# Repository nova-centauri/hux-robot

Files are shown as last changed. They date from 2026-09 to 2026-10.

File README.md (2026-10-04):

# Hux — V1-PROOF

**Build a small wheeled robot that balances, drives and adjusts its height for under $1,000.** The stair project is parked. V1-PROOF is the active model as of 2026-09-28. Old requirements do not gate this build.

| Design target | V1-PROOF |
| --- | --- |
| Cash budget | **$900 planning ceiling**, including $100 shipping/tax and $125 repair contingency; strictly under $1,000 |
| Mass | **2.5 kg target; 3.0 kg maximum**, including battery |
| Actuators | **Four:** two encoder wheel gearmotors, one small leg servo per side |
| First milestone | Pin the legs; balance using only the two wheel motors |
| Size | Approximately **28–31 cm high, 25.5 cm wide**, 10 cm rubber wheels |
| Motion | Indoor mobility; 0.25 m/s cruise, 0.15 m/s on qualified shallow uneven surfaces; approximately 28 mm leg-height adjustment |
| Reuse | Existing controller, IMU, manual input, battery/charger and shop stock when confirmed |
| Finish line | Repeatable balance, five movement types, controlled stops, bounded disturbances and slow height changes |

Start with the **[V1-PROOF plan](docs/v1-proof.md)**, **[model page](tools/living-drawings/index.html)**, **[2D layout](cad/layouts/v1-proof.svg)** and **[budget](docs/bom.md)**. The budget includes replacement allowances because the available parts are still unconfirmed. The [selected hardware](docs/v1-proof-hardware.md), [simulation report](docs/v1-proof-simulation.md), [interactive replay](tools/living-drawings/proof-simulation.html), [drivable 3D sandbox](tools/living-drawings/proof-sandbox.html) and [physical validation protocol](docs/v1-proof-validation.md) define this revision. This is not a fully quoted cart or a validated physical robot.

The scope has no stairs, one-wheel stance, jumps, rough terrain, onboard cameras, autonomy or required onboard Linux computer. Bounded push recovery and shallow indoor irregularities are now explicit qualification targets. In-wheel BLDC, CAN, 8S, carbon spars and the previous large head are no longer requirements. A geared brushed wheel drive is permitted for this proof.

## Working documents

- [Mechanical testing layout and timeline](tools/living-drawings/mechanical-tests.html): movable side/end views, the R01 render, test steps and dated session drafts.
- [Single-leg bench preparation](docs/one-leg-bench.md), [printable geometry template](cad/layouts/one-leg-bench-template.svg) and [session record](docs/checklists/one-leg-bench-session.md)
- [Requirements](docs/requirements.md) and [decision log](docs/decisions.md)
- [Mechanical](docs/mechanical.md), [electronics](docs/electronics.md), [software](docs/software.md)
- [Parts to confirm](docs/parts-on-hand.md) and [next work](NOTES.md)
- [Build checklists](docs/checklists/), [sizing calculations](docs/v1-proof-sizing.md)
- [Writing standard](docs/writing-standard.md): all active text obeys Simplified Technical English
- [Model source and checks](tools/v1-proof/README.md)

## Living website

The website organizes **V1-PROOF** into Overview, Mechanical, Electrical, Build & test, Parts & budget, and Documents. The interactive tools and the rendered guides have the same navigation. Mechanical includes [joint close-up studies](tools/living-drawings/joints.html). Electrical contains the [source-checked EL-01–04 wiring atlas](tools/living-drawings/electrical.html), with zoomable vector sheets and a printable PDF. [Pinout verification and open circuit decisions](docs/wiring-atlas.md) keep the physical release boundary.

The [build board](tools/living-drawings/build.html) tracks the supported single-leg exercise, the milestone gates and the dated updates. [Parts and budget](tools/living-drawings/parts.html) keeps procurement separate. **V0-GENESIS** remains the original plan archive. Browser bench notes are local drafts. The shared plan is in `tools/living-drawings/plan-data.json` with its referenced documents.

Run `npm run build` and `npm run test:site` from `tools/living-drawings`. Then serve or publish `dist/site`. Markdown guides become real HTML pages with version navigation. Refer to [website maintenance](docs/site-maintenance.md) for the update and preview workflow.

## Parked work

The [V0-GENESIS archive](docs/archive/stair-v1/README.md) keeps the earlier plans (historically named STAIR-V1). The earlier research, the H1 layout, the actuator studies and the old eight-axis simulator remain available as historical work. They do not define V1-PROOF, and this proof chassis has no promised stair upgrade path.

Regenerate the active model with `python3 tools/v1-proof/review.py --write`. Check it with `python3 tools/v1-proof/test_review.py` and `python3 tools/v1-proof/review.py --check`. From `tools/living-drawings`, `npm test` checks the active model. `npm run test:legacy` keeps the old regression suite. This repository contains the plan, the size calculations and a reproducible pinned-leg 3D simulation study.

**2026-10-02: the 30:1 gearmotor and the DRV8874 drivers are received, and the parts are 3D printed**, per the user. Start the [first mechanical fit session](docs/checklists/2026-10-02-mechanical-fit.md). The paid record covers one Pololu 4752 gearmotor and one Pololu 4035 driver. The total delivered driver count remains to confirm. Two ST3215 servos are paid, with the 12 V variant confirmed and the arrival unreported.

**2026-10-03: one Pico 2 with pre-soldered headers is received. The LSM6DSO IMU is also received, untested, per the user.** Start the [Pico USB/LED check](docs/checklists/2026-10-03-pico-bringup.md). The $30.58 controller/IMU order brings the **recorded spend to $173.70** and leaves **$726.30** under the $900 plan. The charge breakdown of the new order is unshown.

These actuator models are locked for V1-PROOF. A second wheel motor is still necessary. Refer to [paid orders](docs/purchases.md), [motor connections](docs/v1-proof-hardware.md) and [how the intelligence works](docs/software.md). RobStride actuators are intended for the future full-size Hux. Fit, load, firmware and balance qualification remain open. [MIT](LICENSE).

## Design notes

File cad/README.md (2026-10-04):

# Hux CAD and layouts

Active: [V1-PROOF envelope sketch](layouts/v1-proof.svg), generated from [model.json](../tools/v1-proof/model.json). It shows side, front and plan envelopes plus the simple parallel-link leg. It is not a fabrication drawing or a clearance validation.

For bench geometry checks, use the [1:1 single-leg geometry template](layouts/one-leg-bench-template.svg) with the [bench plan](../docs/one-leg-bench.md). Print at actual size and make sure that the 100 mm scale is correct. The template marks pivot centers for a paper/scrap mockup. Shaft holes, structural sections, lateral offsets and purchased-part mounts are not released.

**2026-10-02 — parts printed and motor/drivers received per the user:** start the [first mechanical fit session](../docs/checklists/2026-10-02-mechanical-fit.md). The [V1-PROOF R01 passive kit](prints/v1-proof-r01/README.md), drafted on September 29 for the Bambu X1C and PLA, has eight STL part types. The kit also has a Blender project that uses the 110 mm link / 40 mm pivot geometry. Confirm the printed revision and material, measure the fit coupon if it is printed, and check the actual M4 fits. Printed sections and mounts remain provisional. No fit, load test or bench milestone is complete.

Next: measure the available parts, mock up the pinned-leg chassis, then detail bearings, pivots, reductions and cables for one leg. Keep 2D layouts before detailed 3D work. Suitable scrap/COTS stock is welcome. There is no carbon or custom in-wheel motor requirement.

[H1](layouts/head-h1.svg), the [stair engineering review](../docs/head-and-leg-review.md), old sheets and downloaded vendor geometry are parked references. Vendor files in `vendor/` remain untouched and do not establish ownership. No released Hux custom parts exist.

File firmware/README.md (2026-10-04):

# Firmware

No embedded implementation exists yet. **2026-10-03:** one Pico 2 with pre-soldered headers is received, untested. Start the [USB/LED bring-up checklist](../docs/checklists/2026-10-03-pico-bringup.md) with the official vendor examples.

V1-PROOF targets C/C++ with `PICO_BOARD=pico2`. The target also includes the received LSM6DSO IMU over SPI, two encoder wheel drivers and, later, two small leg servos. Sensor qualification is not complete. The LSM6DSO IMU replaces the earlier LSM6DSOX selection. Use the register initialization of the LSM6DSO IMU. [Software contract](../docs/software.md) and [software checklist](../docs/checklists/software-bringup.md).

Robot modes are `DISARMED`, `BALANCE`, `DRIVE`, `FAULT`. A proposed `BENCH_ARMED` state supports a rigidly fixed single leg and a lifted wheel before balance. Refer to the [bench controls and test plan](../docs/one-leg-bench.md). No bench controller exists. CAN, one-wheel stance modes and stair control belong to the parked project.

First jobs can be readback, bounded actuator motion and fault checks in the fixture. Then sensor logs and pinned-leg balance can follow.

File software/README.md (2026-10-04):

# Companion software

V1-PROOF needs no onboard companion computer. Use an available laptop for logs and optional timed manual commands. An available Pi can help off-robot, but cameras, ROS, pathfinding and new compute purchases are deferred.

The MCU runs the balance loop. [Active software plan](../docs/software.md). No companion implementation exists yet.

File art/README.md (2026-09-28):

> **PARKED STAIR-V1 — 2026-09-28.** This is historical research, not an active requirement, BOM or build gate. [V1-PROOF](../docs/v1-proof.md) governs current work.

# Art

Exploratory visuals for Hux, made to look at before any accurate model work. These are concept renders and image-to-mesh studies. They are not measured geometry, they do not meet the 2D-layout gate, and they stay out of `cad/`.

Proportions, joint axes, and part envelopes still live in `docs/mechanical.md` and the living drawings. The same files are on the [media page](../tools/living-drawings/media.html).

## Concepts

| File | What it shows |
| --- | --- |
| `concepts/hux-standing.jpg` | Studio three-quarter. Style anchor: carbon-tube legs, aluminum knee linkages, black cubes at the hips, spokeless disc hubs, battery box, camera on top. |
| `concepts/hux-knee-actuators.jpg` | Same machine with black cubic actuators at the knees in place of the linkage plates. |
| `concepts/hux-straight-leg.jpg` | Earlier packaging sketch: one spar per leg, finned hip motors, no knee. |
| `concepts/hux-side.jpg` | Side view. The camera sits slightly off a true elevation, so both wheels still show. |
| `concepts/hux-workshop.jpg` | The standing robot in a shop, with stairs behind it. |
| `concepts/hux-stairs.jpg` | Climb, one wheel on a higher tread. |
| `concepts/wheel.jpg` | Wheel study. The motor sits beside the hub in this sketch. |
| `concepts/leg.jpg` | One leg: paired carbon tubes, linkage knee, cube at the hip, disc wheel. |
| `concepts/torso.jpg` | Hip beam, two side cubes, battery, camera. Legs removed. |

## Models

Rough textured meshes generated from the isolated shots. Each file is a single mesh, on the order of a million triangles, 45–74 MB. Fasteners melt together, edges go soft, and a little floor tone can bake into the texture. Any glTF viewer will open them.

| File | Source image |
| --- | --- |
| `models/hux.glb` | `hux-standing.jpg` |
| `models/leg.glb` | `leg.jpg` |
| `models/wheel.glb` | `wheel.jpg` |
| `models/torso.glb` | `torso.jpg` |

## Where the pictures drift from the mechanical notes

- Nothing here is to scale. The paper envelope is about 24 in tall and 14 in wide, with 6 in wheels.
- The battery is drawn high on the torso. The mass sketch wants it low and central.
- Several shots put the wheel motor beside the tire. The intent is a motor in the hub.
- Hip roll and hip swing are not drawn as two separate joints.
- Small print on the battery, tire sidewalls, and plates is gibberish. Ignore it.

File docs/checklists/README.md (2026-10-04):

# V1-PROOF build checklists

The active checklists are for the small, four-actuator indoor proof with bounded disturbance and shallow-surface qualification. [Finish line](../v1-proof.md#finish-line).

- [Mobility and disturbance protocol](../v1-proof-validation.md)
- [Hardware decisions and interfaces](../v1-proof-hardware.md)
- [Single-leg bench plan](../one-leg-bench.md) and [copyable session record](one-leg-bench-session.md)
- [First mechanical fit session, opened 2026-10-02](2026-10-02-mechanical-fit.md): the motor/drivers and the printed parts are received. The passive checks are ready. No results are recorded yet.
- [Living mechanical layout and test timeline](../../tools/living-drawings/mechanical-tests.html) and [recording workflow](../mechanical-testing.md).
- [Mechanical stages and trials](mechanical-v1.md)
- [Electronics bring-up](electronics-bringup.md)
- [Software bring-up](software-bringup.md)
- [Pico 2 USB bring-up, opened 2026-10-03](2026-10-03-pico-bringup.md): the controller is received. The LSM6DSO IMU is also received, untested, per the user. The BOOTSEL, LED and optional serial results are not recorded yet.

Check a box only after physical evidence exists. Previous stair checklists are [parked](../archive/stair-v1/checklists/README.md).

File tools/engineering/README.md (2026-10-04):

> **PARKED STAIR-V1.** [V1-PROOF](../v1-proof/README.md) is the active numerical model. This publisher cannot overwrite the proof BOM.

# Parked stair engineering candidate — revision 2026-09-28-B

No components are purchased. There is no fabrication or full actuator-set release. Start with
[the review](../../docs/head-and-leg-review.md) and
[decisions](../../docs/decisions.md). No third-party Python packages are necessary.

```sh
python3 tools/engineering/review.py --write
python3 tools/engineering/test_review.py
```

`baseline.json` owns head allocations, mass estimates, geometry, study overrides,
electrical assumptions and the historical tube reference. `bom.json` owns budget
rows and their procurement gates. Generated outputs:

- `docs/research/head-leg-results.json`: results and 91-frame paths for the compact, extended and narrow-entry candidates. The other cases have summaries only.
- `cad/layouts/head-h1.svg`: dimensioned head allocation.
- `tools/living-drawings/engineering.html`: parked stair review page.
- `docs/archive/stair-v1/bom.md`: archived budget, computed from quantities and unit ranges.

Coordinates in the input and result positions are **mm**, X forward, Y left, Z up.
The body datum is midway between the hip-roll axes. Inertia is kg·m², torque N·m,
mass kg, force N. `angles_deg` orders hip roll, hip pitch, knee flexion, ankle roll.
Positive pitch puts the thigh rearward. The shin pitch is `hip_pitch − knee`.

Left and right legs use opposite lateral offsets. In a selected upright wheel
pose, the assumed ankle counter-roll equals negative hip roll. This assumption depends on an
unbuilt pitch-level carrier, not on a motor bolted to the shin.

`leg` is the compact 24-inch target. The `studies.taller_leg_overrides` and then
`studies.extended_leg_overrides` form the approximately 27-inch wide-entry comparison. The `studies.narrow_stance_overrides` produce the narrow comparison: 120 mm track during the step plus a nominal 355.6 mm moving-width gate.

`neutral_wheel_outside_width_mm` defines the fixed axle/yoke offset at zero roll, not the swept envelope. The preferred candidate uses the 9.5-inch link override with that narrow stance, for 25.94-inch height.
The 24/25-inch narrow cases remain rejected. The high-mass
case adds the explicit 0.60 kg head uncertainty. Neither variant silently replaces
the requirement. The `release` flags of the report stay false, whatever the screen scores are.

The screen solves whole-robot static COM, split-offset spatial IK and gravity joint
moments. A layered search connects feasible poses. Interpolation checks the limited
clearance model between samples. The screen does not solve actuator dynamics, real contact
compliance/friction, thermal duty, full swept solids, nosings, descent or the actual
ankle linkage. The old eight-axis JavaScript simulation remains a labeled historical
experiment. Its tests intentionally assert that its stair candidate fails.

When you accept a design revision, update the inputs and the dated decision entry. Then
regenerate the outputs and check the physical invariants. Update requirements, CAD joint
centers, inertia/contact model, BOM, firmware map and limits together. Never
promote an unmeasured mass or a vendor heat-sink rating into a hardware fact.

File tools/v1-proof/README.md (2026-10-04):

# V1-PROOF numerical studies

Four actuators, 2.5 kg target / 3.0 kg maximum, indoor mobility and bounded disturbances, strictly under $1,000. [Plan](../../docs/v1-proof.md) · [hardware decisions](../../docs/v1-proof-hardware.md).

```sh
python3 tools/v1-proof/review.py --write
cd tools/living-drawings
npm ci
npm run simulate
npm test
```

`model.json` owns hardware selections, dimensions, mass, electrical screens, operation targets and budget. Standard-library `review.py` generates the BOM, the size calculations, the SVG, the results and the plan data for the browser. Its `--check` finds stale outputs.

`sim.js` builds the pinned-leg 3D rigid-body model and controller with the pinned Rapier 0.20.0 dependency of the repository. It imports no legacy stair motors, masses or joint model. `run_sim.js` runs 23 scenarios across 17 configurations, six challenge cases, five timestep comparisons and six separate CoM-adjustment checks. `--quick` runs nominal/challenge/convergence only. Use `--write` without `--quick` for published evidence. `--check` makes sure that the saved source hashes are correct.

`report_sim.py` generates the [evidence report](../../docs/v1-proof-simulation.md). [Interactive replay](../living-drawings/proof-simulation.html).

**3D sandbox.** [`proof-sandbox.html`](../living-drawings/proof-sandbox.html) loads this same `sim.js` in the browser (`HuxProofSimFactory(RAPIER, model)`). You drive it from the keyboard or a gamepad at full scale, on the fixtures of the physical protocol (3° grade, 3° cross-slope, 5 mm bumps, 3 mm seam, 20 mm challenge threshold). [`proof-sandbox-core.js`](../living-drawings/proof-sandbox-core.js) adds only the fixtures, lane starts, robot-frame shoves, fall detection and a slow leg-height preview. `test_sandbox.js` checks it headless and runs in `npm test`. The leg preview re-places the CoM and pitch trim at 10°/s. The sandbox does not model servo dynamics, so legs that move are not evidence.

The sandbox adds nothing to `sim-results.json`. The page opens correctly straight from disk. three.js and Rapier load from jsDelivr.

`npm test` covers budgets/geometry plus gravity without control, mass, contact, voltage/speed/current bounds, balance-priority steering, signed maneuvers and deterministic reruns. The full sweep is explicit with `npm run simulate`. Failed cases remain in the report. `sim-tuning-history.json` keeps the weaker results of the initial controller.

The simulation assumes delayed attitude estimates and bounded torque response. It does not implement raw IMU fusion, MCU firmware, a thermal model, regenerative power electronics or powered leg dynamics. Read the assumptions of the report before you quote outcomes. All [physical tests](../../docs/v1-proof-validation.md) remain open. The previous stair model is parked separately.

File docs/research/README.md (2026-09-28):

> **PARKED STAIR-V1 — 2026-09-28.** This is historical research, not an active requirement, BOM or build gate. [V1-PROOF](../v1-proof.md) governs current work.

# Research first

**Current engineering baseline (2026-09-28):** [head and leg review](../head-and-leg-review.md), [reproducible numerical results](head-leg-results.json), [decision log](../decisions.md). Older research below is dated evidence, not current purchasing or fabrication authority. No Hux components purchased.

Hux is still early R&D. **Study before we build.** Watch, read, extract control and stair heuristics, then decide what to adapt versus rewrite. Do not vendor James Bruton / [XRobots](https://github.com/XRobots) trees into this repo yet. Do not spend. Flight controller stays **TBD**.

This packet is the working study set. It does not replace [`../requirements.md`](../requirements.md) or [`../vision.md`](../vision.md).

| Doc | What it is |
| --- | --- |
| [model-corrections.md](model-corrections.md) | Implemented geometry, contact, actuator, parking and reporting fixes; current regression results and remaining design work. |
| [real-world-validation.md](real-world-validation.md) | 2026-09-23 audit: spatial reach inconsistency, CoM versus hip torque, actuator/contact limits, reproduced tests, and physical validation sequence. Read before using earlier sizing or stair claims. |
| [xrobots.md](xrobots.md) | Curated XRobots shortlist, why each matters, study order |
| [inspiration.md](inspiration.md) | Steve's shares — Roadrunner, FrRonconi student balancer, Serra / Build Some Stuff, Tazer, Stompy, Diablo, SpdrBot; inspiration only |
| [roadrunner.md](roadrunner.md) | RAI Institute Roadrunner — lab wheeled biped; watch alongside Hattori |
| [actuators-legs.md](actuators-legs.md) | Axis-role trade; hip roll in V1; servo vs stepper TBD; GIM8108-8 candidate |
| [tazer-lessons.md](tazer-lessons.md) | Tazer wheeled biped — learn from the mistakes (anti-patterns) |
| [stompy-sim2real.md](stompy-sim2real.md) | Stompy week-build RL walker — CAD/reality match, shared zero; **not** RL walking for Hux V1 |
| [diablo.md](diablo.md) | Diablo (DDTRobot) — commercial wheeled-leg; LQR + DD; steal split brain / height states; **do not buy** |
| [spdrbot.md](spdrbot.md) | SpdrBot — Isaac Sim / Lab 4-leg spider; Fusion→URDF→USD; RL then hand gait; Phase E pipeline lessons, **not** a spider |
| [leg-geometry.md](leg-geometry.md) | Leg math. Wheel settled at **6" OD** on a **9.5" × 9.5"** step. Walker wheel is a bench donor. |
| [stair-climb-dynamics.md](stair-climb-dynamics.md) | Corrected spatial feasibility, rejected stair candidate, and limits of the historical planar load estimates. |
| [sim-sandbox.md](sim-sandbox.md) | Corrected tire/contact and drive models, supported parking guard, regression results, and remaining single-support failures. |
| [one-leg-stance.md](one-leg-stance.md) | Frontal-plane mechanics of the hip-roll weight shift (24.7°, 8.3 N·m hold), why a static one-wheel stand is an acrobot with millimetres of capture region, and the dynamic single-support flight budget the stair needs (≤ 0.3 s). |
| [compute-stack-review.md](compute-stack-review.md) | 2026-09-26 review of the F765-Wing / SimpleFOC / Pi 5 bench stack and the Jetson question — no CAN on the Wing, actuator bus picks the MCU, Jetson is a P5 perception buy, not V1 |
| [actuator-shortlist.md](actuator-shortlist.md) | 2026-09-26 decision framework and candidates on Hux's own numbers — RobStride 00/02/05 shortlist, the 24 V floor that pushes the pack to 8S, CAN bus math, runtime vs pack size |
| [knee-linkage.md](knee-linkage.md) | 2026-09-26 — knee actuator at the joint vs at the hip through a linkage vs no knee (four-bar / five-bar legs à la StepByStep, Ascento, T-REX); planar check on the settled draw; keep 2 DoF per leg, no five-bar, draw the hip-driven knee on the 2D sheet |
| [study-plan.md](study-plan.md) | Phased checklist before hardware (Phases A–D; Phase E twin / dojo is a later horizon) |

Decision log (not research, but the lock list): [`../decisions.md`](../decisions.md).

Inspiration already in requirements: [Alex Hattori — STRIDE wheeled biped V2](https://www.alex-hattori.com/blog/wheeled-biped-v2).

Steve's shares (inspiration only; not a build source): [inspiration.md](inspiration.md) — [Roadrunner](roadrunner.md) (lab), the FrRonconi 3-month student two-leg/wheel balancer (closer Hux vibe), Serra / Build Some Stuff (steal packaging), [Tazer](tazer-lessons.md) (learn from the mistakes), [Stompy](stompy-sim2real.md) (CAD → sim → real; **not** an RL-walking requirement), [Diablo](diablo.md) (commercial wheeled-leg; **do not buy**; keep R18), and [SpdrBot](spdrbot.md) (Isaac Sim / Lab pipeline for the Phase E horizon; **not** a spider; **not** Isaac before `TWO_WHEEL`).

## Stance

1. **Learn the lineage** — RobotX (wheeled biped / dynamic balance), then TallBalancer and SonicRobot for IMU → PID → wheel-torque and remote patterns.
2. **Map stairs** — XRobots Stairs is a different mechanism. Steal heuristics, not geometry. Pair it with Hattori (and [Roadrunner](roadrunner.md); see [inspiration.md](inspiration.md)) for Hux's lift → one-leg balance → plant cycle on a **~9.5"** riser. Serra is packaging, not stairs.
3. **Decide license + adapt vs rewrite** — Steve decides. Do not relicense Hux to absorb copyleft code, and do not pretend GPL/LGPL sources are MIT.
4. **Only then** print a wheel-leg fit-check. Mechanical V1 is Phase D, not the next commit.

No purchases until Steve asks. Prefer parts already on hand. Do not invent a BOM from upstream parts lists (SonicRobot's README is a study aid, not a Hux shopping list).

## How we cite and adapt upstream

Respect each upstream license. XRobots repos are **not** one license. RobotX is the copyleft tripwire for this phase.

### Cite

When a note, sketch, or later file is informed by upstream, record:

- Project name and org (`XRobots/RobotX`, Hattori STRIDE V2, RAI Roadrunner, FrRonconi / student balancer, Build Some Stuff / Serra, Tazer, Stompy / Kayden Knapik, Diablo / Direct Drive Tech, SpdrBot / Indystry, …)
- URL (repo, playlist, or post)
- License as stated by the author **and** the `LICENSE` file if they disagree
- What we took (idea, heuristic, control topology) versus what we did **not** copy

### Study vs vendor

| Allowed now | Not allowed yet |
| --- | --- |
| Watch playlists, read CAD/code in *their* repos | Copy CAD, firmware, or large trees into Hux |
| Notes, diagrams, and checklists in `docs/research/` | Treat upstream parts lists as a Hux BOM |
| Rewrite a loop from understanding (clean-room) | Drop GPL/LGPL sources next to our MIT tree |
| Link and quote short facts with attribution | Relicense anyone's code, including Hux itself |

Vendoring or adapting code is a **Phase C** decision. Until Steve picks a path, this repo stays MIT documentation and empty layout.

### RobotX is GPL3 — implications for MIT Hux

Hux is [MIT](../../LICENSE) (Steve Barrett, 2026).

[XRobots/RobotX](https://github.com/XRobots/RobotX) README states:

> All CAD and code is licensed under GPL3.

The repo also ships an **LGPL-3.0** `LICENSE` file. GitHub therefore labels the repo LGPL-3.0. **Do not resolve that conflict in Hux's favor.** Conservative reading for this phase: treat RobotX CAD/code as **GPL-3.0** as the author wrote in the README, and treat the LGPL file as an unresolved ambiguity Steve must look at before any vendor/adapt.

If we later **vendor or adapt** RobotX (or other GPL) code into Hux:

- We **cannot** relicense that material as MIT.
- A combined Hux tree that includes GPL-3.0 code is typically distributable only under GPL-3.0 (copyleft applies to the derivative).
- Even if the LGPL file controls, modified RobotX sources stay copyleft; LGPL is not a free pass to relicense or to hide provenance.
- MIT Hux and GPL RobotX can coexist as **separate** repos we study. Mixing them in one tree is the problem.

**Do not relicense Hux (MIT → GPL) or relicense upstream (GPL → MIT) without Steve deciding.** Phase C exists so that decision is explicit.

Other copyleft in the shortlist (still study-only):

- [XRobots/SonicRobot](https://github.com/XRobots/SonicRobot) — GitHub license **GPL-2.0** (closest brushless + balance electronics lessons)
- [XRobots/BalancingStrandbeest](https://github.com/XRobots/BalancingStrandbeest) — **GPL-3.0** (optional)

Several secondary XRobots repos are MIT (TallBalancer, Stairs, YouCanBuildBiPed, BallWheels, BeltWheelRobot, Ball-BIke, Mid-Walker). MIT-to-MIT adaptation still needs attribution and a Phase C yes; it does not force Hux off MIT.

Watching, learning, and rewriting from understanding is the default path that keeps Hux MIT. Copying RobotX or SonicRobot sources is the path that forces a license decision.

## Out of scope for this packet

- Locking an FC
- A Hux BOM or shopping list
- Vendoring `XRobots/*`
- Starting the first wheel-leg before Phase D
- Opening Blender before 2D layouts (R23)
- Changing [`../vision.md`](../vision.md) without a Steve decision (log it in [`../decisions.md`](../decisions.md))

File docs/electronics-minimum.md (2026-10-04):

# Minimum electronics — V1-PROOF

The active minimum is **one MCU + IMU, two encoder wheel motors, two bidirectional H-bridges, a timed manual input link, and a compatible battery/charger**. **The minimum also includes protected logic power.** Add two small leg servos and their interface/rail after pinned-leg balance works.

Start with the equipment confirmed in [parts-on-hand.md](parts-on-hand.md). There is no required Pi, CAN network, 8S pack, camera or separate pose computer. The [electronics plan](electronics.md) owns the interfaces and the power qualification. The [budget](bom.md) covers replacements. The former eight-axis minimum is [parked](archive/stair-v1/electronics-minimum.md).

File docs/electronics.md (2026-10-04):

# V1-PROOF electronics

**Selected baseline: Pico 2, the LSM6DSO IMU on SPI, two DRV8874 drivers and two ST3215 servos (12 V variant).** [Exact interfaces, proposed GPIO map, component sources and qualification gates](v1-proof-hardware.md). Confirmed equivalent equipment on hand can reduce the spend only after it meets the same contract. No onboard Linux computer or camera is necessary.

The [Electrical page](../tools/living-drawings/electrical.html) now contains the color-coordinated **EL-01–04 wiring atlas**, with an enlarged vector viewer and a printable PDF. The [source checks and detailed pin maps](wiring-atlas.md) separate the vendor-confirmed pinouts from the proposed GPIO assignments and the unresolved circuits. This is a build-plan drawing. The physical harness and the power-protection release remain open.

**Status, 2026-10-02:** the user reports that the 30:1 motor and the DRV8874 drivers are received and that the parts are printed. Receipts cover one Pololu 4752 gearmotor and one DRV8874 driver. The total received driver count remains to confirm. Two ST3215 servos are ordered, with the 12 V variant confirmed and the arrival unreported. A second wheel motor is still required. Confirm the driver coverage before you buy another driver.

The controller, IMU, adapters and power electronics remain purchase-unconfirmed. [Receipts and delivery status](purchases.md). Start with the [passive mechanical fit checks](checklists/2026-10-02-mechanical-fit.md). This wiring plan still waits for assembly and bench checks.

**2026-10-03:** one Pico 2 with pre-soldered headers is received, untested. The user reports that the LSM6DSO IMU is also received, untested. It replaces the earlier Adafruit LSM6DSOX selection. Start the [board-only USB/LED checks](checklists/2026-10-03-pico-bringup.md). Before you connect the sensor wires, examine the received IMU pads/jumpers and use 3.3 V power/logic.

## What will the motor plug into?

**Each Pololu 4752 gearmotor connects to its own DRV8874 driver (an H-bridge) through a breakout harness.** The driver switches the battery power through the motor. The Pico 2 sends low-power direction/PWM commands. The encoder wires of the motor return the movement feedback to the Pico 2 through level conversion.

The supplied connector of the Pololu 4752 gearmotor is a six-position female header at 2.54 mm pitch. It contains both the motor wires and the encoder wires. It needs a correctly wired mating header/harness. It is not a ready-made Pico 2 plug or servo-bus plug. [Pololu motor connector and wire reference](https://www.pololu.com/product/4752).

| Motor lead | Planned connection |
| --- | --- |
| Red | Driver OUT1 motor terminal |
| Black | Driver OUT2 motor terminal; this is a switched motor lead, not encoder ground |
| Green | Encoder ground / common logic reference |
| Blue | Regulated 5 V encoder supply |
| Yellow | Encoder A → 5 V-to-3.3 V level conversion → Pico encoder input |
| White | Encoder B → 5 V-to-3.3 V level conversion → Pico encoder input |

Repeat for the other wheel. Make sure of the connector orientation by wire function. Establish the forward/encoder sign of each wheel while the wheel is lifted. The harness, the lock/strain relief and the high-current connections still need fabrication. Keep the motor current out of breadboards and MCU supply pins. The proposed Pico 2 GPIO assignment is in the [hardware plan](v1-proof-hardware.md#interfaces-that-must-be-built-correctly).

The first driver for this motor was in the same Pololu shipment as the motor. The user reports that both are received, and the total driver count is not yet confirmed. The driver takes fused, switchable motor power at VIN/GND. It accepts the 3.3 V signals of the Pico 2: PWM to EN, direction to PH, with PMODE grounded. Its SLEEP input is the watchdog/kill-gated output-disable path.

The driver needs soldered connections or headers. It is a separate power board. Set and measure the current limit before you run a motor. [Pololu driver connections](https://www.pololu.com/product/4035).

**The ST3215 servo uses a different connection:** the protected 9 V servo branch supplies the power. A compatible half-duplex TTL interface carries the serial commands and the feedback between the servo bus and the Pico 2 UART. Assign distinct servo IDs and examine the received cable pinout before you power either unit. An H-bridge is for the brushed wheel motors. Each ST3215 servo already contains its own motor control electronics. The interface/adapter is still to be confirmed.

## Power and command paths

```text
3S pack -> fuse + physical actuator-power cut
  -> two DRV8874 H-bridges -> Pololu 4752 encoder gearmotors
  -> regulated/protected 9 V branch -> two ST3215 leg servos
  -> separate 5 V logic regulator -> Pico 2 + 3.3 V IMU/interface logic
Pico <- SPI IMU + 5 V encoder signals through level conversion
Pico <- both driver current/fault signals + divided pack voltage
Pico -> PWM/direction + watchdog/kill-gated SLEEP -> wheel drivers
Pico <-> half-duplex UART transceiver -> servo bus
Pico <- timed manual commands / deliberate arm
Pico <-> USB serial -> existing laptop logging/gamepad
```

## Power and interfaces

Keep the motor/servo current out of the controller PCB. Make sure of the common signal reference, connector ratings, fuses, wire gauge, strain relief and local capacitance. The 9.9 V simulation input is a size-calculation point. Measure the actual pack condition and the loaded cutoff. The battery, charger, regulators and energy clamps are not yet released circuits.

Target a 9 V servo branch that can supply approximately 6 A as a short peak for both servos at the same time. Then qualify the actual duty at the lowest loaded output. Protect every branch against regenerated energy. Ordinary regulators and bench supplies do not necessarily absorb it. Do not connect the selected 12 V servo variant directly to an unprotected, fully charged 3S bus. The mounted servo hold duty must pass at 9 V.

Set both wheel drivers to PH/EN with **PMODE low and IMODE directly grounded**. This keeps the normal current chop separate from a reported driver fault. Measure the 2.5 A peak current threshold, the response at reversal and the PWM-synchronized current sense. Start with a 1.2 A RMS limit and qualify the temperature and the pulse duration. Do not infer the actual current from the PWM duty. Pull the fault outputs up to 3.3 V.

The fault and watchdog behavior latch at the robot controller and need a deliberate rearm.

The motor encoders need a suitable 5 V supply and level conversion to the Pico 2. The SPI IMU uses a data-ready interrupt and timestamps. The servo bus needs a correct 3.3 V-compatible half-duplex transceiver, not bare TX/RX pins tied together.

## Bring-up order

Do the USB-powered log and the sensor calibration first. Then do one restrained wheel, both wheel channels and the pinned chassis. Before free balance, examine the direction/encoder sign, motor response, current limit, stale data, reset, watchdog and physical kill. Measure a sensor/estimator age ≤6 ms and an effective drive lag ≤10 ms under the worst intended telemetry load. These are study limits to make sure of, not guaranteed component performance.

The TBS Nano is reusable only with a compatible, available transmitter. The initial laptop/gamepad commands use a 250 ms deadman and a slack tether in the fixture. Untethered RC and the ten-minute duty trial are separate physical checks. [Electronics checklist](checklists/electronics-bringup.md).

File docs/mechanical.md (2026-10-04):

# V1-PROOF mechanical plan

Active: a **2.5 kg target / 3.0 kg maximum**, four-actuator robot on two approximately 100 mm rubber wheels. The [old stair mechanism](archive/stair-v1/mechanical.md) is parked. [Envelope sketch](../cad/layouts/v1-proof.svg) · [formulas and mass budget](v1-proof-sizing.md).

Use a simple bolted chassis and suitable scrap/COTS stock. Aluminum flat bar, plywood body plates and tube on hand are permitted. There is no requirement for carbon, a molded shell, a large head, an in-wheel hub or an elaborate battery cassette. Keep the pack and the electronics removable. Include rest skids and a catch fixture.

## Wheel and leg arrangement

One selected Pololu 4752 gearmotor with encoder at each wheel carrier. Use proper hubs, supported axles and a bearing path for the robot weight. An unqualified motor shaft is not automatically a structural axle. Inboard motors are permitted.

Do a check of the complete motor length and the wire-harness sweep before you fix the track. The proposed track is 230 mm and the wheel width is 25 mm. This gives 255 mm across the tires.

Each leg has two 110 mm parallel links. The body pivots and the wheel-carrier pivots have the same 40 mm vertical separation. This makes a planar parallelogram. One leg servo drives one body pivot through a 3:1 belt reduction. The other pivots are passive and have bearings. The link angle is 15–45° rearward from the downward vertical.

Use independent bearings on the driven shaft, hard stops and removable lock pins. This is one powered leg coordinate per side, not independently commanded hip/knee joints.

The upright layout gives 278–306 mm overall height with a 150 mm body allocation above the lower pivot. The nominal vertical travel is 28.5 mm, but the axle also moves 49.3 mm fore/aft. The balance control must allow for the real pose-dependent CoM/pitch trim. Do not describe this as pure vertical suspension or a finished CAD mechanism. Keep both leg commands synchronized at first. To unload one wheel independently is outside the scope.

## Size the load honestly

Use the full mass for the conservative sprung-load screen and a 60/40 two-wheel load split. The proposed 3:1 reduction gives approximately 0.54 N·m worst static servo demand at 3 kg. This is before horizontal forces, acceleration and measured losses. The leg servo must pass a mounted 0.75 N·m hold qualification for 10 minutes and a separate 1.0 N·m transient test. A quoted stall torque is insufficient.

We use no spring credit. Springs are unnecessary for the pinned-leg first milestone.

Measure the mass, the whole-robot CoM, the gear backlash, the tire traction and the pitch trim across the leg range. Reduce the travel, the speed or the mass before you add hardware. A Pi, a larger battery or a heavy shell must fit the same mass budget. There is no payload requirement.

## Fabrication sequence

The user can use the [single-leg bench plan](one-leg-bench.md) and the [1:1 paper template](../cad/layouts/one-leg-bench-template.svg) before these full-robot stages. A clamp holds the body, and a support holds the mechanism when the torque disappears. Detail the lateral link separation. At 15°, the link centerlines are only 10.35 mm apart perpendicular to their length. Thus ordinary coplanar flat bars can collide.

The upper carrier pivot also lies inside the projected radius of the wheel and needs lateral clearance. The current envelope sketch does not resolve either interference.

1. Mock up the body, wheels, full gearmotor envelopes, battery, pivots and wire harness in 2D/scrap.
2. Build the pinned neutral stance (30° link angle) and qualify two-wheel balance.
3. Detail one reduced-servo leg with belt engagement, bearings, stops and cable sweep. Do a load test of it in a fixture.
4. Fit both powered legs and qualify small, slow synchronized height changes.

The sketch does not validate bolts, bearing fits, swept clearance or structure. The detailed dimensions come from the measured available parts. [Build checklist](checklists/mechanical-v1.md).

## Bounded disturbance envelope

The [pinned-leg 3D study](v1-proof-simulation.md) exercises the 230 mm track against longitudinal/lateral pushes and shallow uneven fixtures. Lateral recovery comes from the track width and passive ground contact. There is no roll axis and no active one-wheel recovery. Keep the travel pinned at 30° until the [physical protocol](v1-proof-validation.md) passes. Fixed 15°/45° simulated corners do not validate servo motion, belt compliance or real load distribution. Measured CoM/inertia and tire friction must replace the assumed values before the terrain or the payload increases.

Provide adjustable mounts for the battery/electronics and measure the sprung fore/aft CoM at pinned neutral. Target **within ±2 mm of the nominal balance line** before grade qualification. A near −4 mm offset failed the strict grade-settling gate. Recheck the trim at each fixed height. The full uncertainty matrix keeps its wider ±4 mm corners and their failures.

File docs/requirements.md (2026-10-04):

# V1-PROOF requirements

**Active from 2026-09-28.** The user's scope reset supersedes the stair project. The [archive](archive/stair-v1/requirements.md) keeps the historical R1–R44 requirements. They do not constrain this proof build. [Plan and finish line](v1-proof.md).

| ID | Requirement | Acceptance / scope |
| --- | --- | --- |
| PF01 | Strictly under $1,000 new cash | Entire proof build, all stages, tax, shipping, consumables and repairs; $900 planned ceiling |
| PF02 | Reuse suitable equipment first | Confirm exact items before deducting budget; no assumed free inventory |
| PF03 | Small, lightweight robot | 2.5 kg proposed target; 3.0 kg maximum including battery |
| PF04 | Four powered axes maximum | Two wheels plus one leg adjustment per side; no roll or ankle axes |
| PF05 | First balance with pinned legs | Same structure/wheel/electronics hardware carries into leg-motion stage |
| PF06 | Two-wheel balance and manual drive | 60 s balance 9/10 starts; forward/reverse, left/right arcs and both in-place rotations; [physical protocol](v1-proof-validation.md) |
| PF07 | Modest leg movement, both wheels down | Ten low/high/low cycles; target ≥25 mm measured height change |
| PF08 | Shallow indoor irregularities | At 0.15 m/s: ±3° cross-slope, 3° ascent/descent, 5 mm smooth bump over 300 mm, 3 mm seam; no rough terrain or stairs |
| PF09 | Slow travel | 0.25 m/s cruise; 0.5 m/s remains unqualified; recovery clearance to 0.65 m/s |
| PF10 | Flexible, inexpensive drives | Geared brushed wheel motors and small servos allowed; encoder feedback and mounted duty tests required |
| PF11 | Minimal electronics | Received Pico 2 + SparkFun LSM6DSO baseline; electrical/timing qualification required; zero onboard cameras |
| PF12 | Compatible power and fault handling | Pack/rails verified at full charge and low operating voltage; current limits, physical cut and stale-data handling |
| PF13 | Serviceable shop construction | Existing/COTS stock, removable pack, accessible fasteners, proper bearings and cable strain relief |
| PF14 | Honest model and evidence | Preliminary drawings before detail CAD; measured mass/CoM and trial logs before performance claims |
| PF15 | Ten-minute mixed demonstration | Within mounted thermal/electrical limits and no resets; fault recovery requires deliberate rearm |

| PF16 | Bounded push recovery | Fore/aft 0.8 N·s, lateral 0.4 N·s at 0.20 m height; 50/200 ms pulses, settle within 3 s; larger human shoves unqualified |
| PF17 | Explicit hardware baseline | [Selected components and bench gates](v1-proof-hardware.md); no purchase or physical validation implied |
| PF18 | Foundation for later versions | Versioned telemetry/commands, measured motor/IMU/contact models, retained failures and regression matrix before payload/perception expansion |

PF01/PF02 and the reduced scope come directly from the user's request. The later 2026-09-28 request adds reliable maneuvers, bounded disturbances, component decisions and a path to higher requirements. The numerical test envelopes and the selected components are design decisions that put that request into effect. They are not measured capabilities. Change them deliberately with the [decision log](decisions.md) and [model.json](../tools/v1-proof/model.json). Keep the user's budget and scope.

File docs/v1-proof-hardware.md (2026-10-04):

# V1-PROOF hardware decisions — updated 2026-10-03

**Freeze this component baseline for bench qualification.** The user requested dependable forward/reverse travel, both turns, a turn in place, and bounded disturbance tolerance. The user also requested a useful foundation for later versions. The receipts reconciled September 29 confirm **one Pololu 4752 gearmotor, one DRV8874 driver and two ST3215 servos**. The paid total is **$143.12**. This total includes shipping and tax.

**2026-10-02: the user reports that the 30:1 motor and the DRV8874 drivers are received and that the parts are printed**. The total delivered driver count, the received labels and the printed revision/material remain to record. The user confirmed the 12 V servo variant. The servo arrival remains unreported.

The [purchase evidence](purchases.md) and the [inventory](parts-on-hand.md) track those facts. Start the [passive mechanical fit session](checklists/2026-10-02-mechanical-fit.md).

RobStride is intended for the future full-size Hux. Fit and physical performance remain separate release gates. The [budget](bom.md) keeps a **$900 planning allocation. The allocation includes $100 freight/tax and a $125 repair reserve**, with no assumed reuse credit.

## Ordered parts define the build

**2026-10-03 controller/IMU update:** the Pico 2 with pre-soldered headers is received, untested. The user reports that the **LSM6DSO IMU** is also received, untested. The supplied October 2 order screenshot establishes the model and the combined order total. This IMU explicitly replaces the earlier Adafruit LSM6DSOX selection.

Use the LSM6DSO-specific initialization, and examine the received breakout before you connect the wires. The $30.58 order total brings the recorded spend to **$173.70**. [Pico bring-up and proposed sensor connections](checklists/2026-10-03-pico-bringup.md).

**The Pololu 4752 gearmotors, the DRV8874 drivers and the ST3215 servos (12 V) are the locked purchased baseline**. Design the harness, motor mounts, wheel hubs and leg transmission around these exact models. The robot needs two of each. One wheel motor is received, and a second remains to buy. The drivers are received, with the total count not yet confirmed.

Both leg servos are ordered, with the arrival unreported.

The inspection and the tested condition still need a record. Keep the 100 mm wheel / 3:1 leg-belt concept while we qualify the fit, strength and performance.

The Pico 2 and the LSM6DSO IMU are received, untested. The encoder level conversion, the servo bus interface and the power protection remain **purchase/availability unconfirmed**. The purchased motor/driver pair supports one bench wheel channel, not a complete two-wheel drive system. A substitute actuator or driver reopens this baseline explicitly. A suitable controller found on hand only changes the implementation after qualification. Refer to [what the motor connects to](electronics.md#what-will-the-motor-plug-into) and [how Hux intelligence works](software.md#how-the-intelligence-works).

| Subsystem | Decision | Reason and release condition |
| --- | --- | --- |
| Wheel motors | **2 × Pololu 4752**, 12 V, 30:1, integrated encoders | Keep 100 mm rubber wheels. Bench-test reversals, backlash, current and torque at minimum operating voltage. This is the selected motor, replacing the earlier open motor-class choice. |
| Wheel drivers | **2 × Pololu 4035, DRV8874** | Adjustable current limit suits this motor; default sleep supports disabled startup. Use PH/EN, 3.3 V control, measured 2.5 A peak limit and initial 1.2 A RMS ceiling. Replaces the G2 18v17 reference and saves $60 in allocations. |
| Leg actuators | **2 × Waveshare ST3215, 30 kg-cm @ 12 V variant**, 3:1 belts | Bearing-supported pivots, physical stops and lock pins. **Regulated 9 V branch**; qualify 0.75 N·m hold for ten minutes and 1.0 N·m transient at its lowest loaded output. No credit for the advertised 12 V stall torque at 9 V. |
| Controller | **Pico 2, RP2350, non-wireless; pre-soldered headers; C/C++** | One received 2026-10-03, untested. Concrete firmware target with encoder PIO, SPI, UART and USB logging. Begin USB/LED checks before attaching external hardware. |
| IMU | **SparkFun LSM6DSO Qwiic, SEN-18020; main SPI + data-ready interrupt** | Received per user 2026-10-03, untested; replaces Adafruit 4438 LSM6DSOX. Raw six-axis data; estimator runs on the MCU. Retain initial ±4 g, ±500°/s, 833 Hz sensor output and timestamped 500 Hz control as unmeasured targets. Use 3.3 V power/logic and verify breakout pads/jumpers. |
| Other feedback | Both wheel encoders, both driver CS/fault outputs, divided pack voltage, servo position/voltage/load feedback | Encoders on the motor side do not measure gearbox play or wheel slip. Verify leg home mechanically; servo feedback does not prove belt integrity. No magnetometer or distance sensor is required for manual proof trials. |
| Cameras | **Zero onboard cameras for V1-PROOF** | Use an existing external phone/camera to measure paths and record trials. No vision dependency in balance. V2 perception gets its own mass/power budget and camera decision after mobility passes. |
| Operator input | Existing laptop/gamepad via USB serial deadman for the fixture; qualified existing RC for untethered driving | Timestamped speed/yaw commands, deliberate arm, 250 ms command timeout. Keep a tether slack and overhead; tether forces invalidate a successful trial. A new full RC system is not assumed to fit the $60 allowance. |
| Power | **3S, approximately 2.2 Ah; separate 9 V servo and 5 V logic branches** | Exact reused battery/charger remain an inventory decision. Protection/regulator allowance increases from $45 to $65. A new nominal capacity does not prove discharge capability or pack health. |
| Structure | 230 mm track, 100 × 25 mm rubber tires, 110 mm parallel links, four total axes | First driving configuration is pinned at 30°. Keep electronics, wheel carriers and battery accessible. Tires/hubs/bearings are dimension-locked, not a falsely specified shopping cart. |

Primary specifications: [motor and encoder](https://www.pololu.com/product/4752), [driver carrier](https://www.pololu.com/product/4035), [ST3215 variants](https://www.waveshare.com/product/st3215-servo.htm), [Pico 2](https://www.raspberrypi.com/products/raspberry-pi-pico-2/), [SparkFun LSM6DSO breakout](https://www.sparkfun.com/sparkfun-6-degrees-of-freedom-breakout-lsm6dso-qwiic.html), [ST LSM6DSO register/data-rate reference, hosted by SparkFun](https://cdn.sparkfun.com/assets/c/f/9/d/1/lsm6dso_datasheet.pdf). We checked the Pico 2 USB instructions and the LSM6DSO specifications on 2026-10-03. We checked the motor wires and the driver interfaces again against Pololu on 2026-09-29. We checked the other selection specifications on 2026-09-28.

Vendor stock labels do not establish what shipped in this order. The [inventory](parts-on-hand.md) records the purchase status of the user separately.

## Interfaces that must be built correctly

The encoder gives **1920 counts per output revolution** with both edges of both channels. Power it at 5 V and convert its A/B signals to 3.3 V. Its specified supply starts above 3.3 V. Do not connect the 5 V outputs directly to the Pico 2. At 100 mm wheel diameter, one count is approximately 0.164 mm. Estimate the speed over several samples, and keep the low-latency position counts.

Set the DRV8874 **PMODE low** before enable. Set **IMODE directly to ground** for fixed-off-time regulation. In its default 20 kΩ state, IMODE reports the routine current chop on nFAULT. Do not confuse that report with a latched robot fault. Add a 3.3 V pull-up to each fault output.

Add a physical actuator-power cut and a hardware watchdog gate on **SLEEP**. Add an MCU fault latch that needs a deliberate rearm. In PH/EN mode, EN low brakes. SLEEP low disables the outputs. The automatic retry of the driver never authorizes a robot rearm.

Start the VREF calculation near 2.8 V with the 2.49 kΩ CS resistor of the board. Then measure the threshold and the tolerance.

An approximate divider is not a calibrated current limit. [TI current regulation and fault modes, Table 6](https://www.ti.com/lit/ds/symlink/drv8874.pdf).

Use PWM-synchronized CS samples and an instrumented motor-current check. Confirm the current sense during drive, brake and reversal before you derive the RMS current or close a current loop. The bounded torque response of the simulation is a bench target, not an implemented torque controller.

Use a correct 3.3 V-compatible half-duplex transceiver with direction control for the TTL servo bus. Validate the servo rail at the demand of both servos at the same time. Design the rail for approximately a **6 A short peak**. Make sure of the regulator thermal duty, the brownout margin and a defined return-energy clamp.

Do not assume that an ordinary buck regulator or a bench supply absorbs regenerated energy. The pack, the motor bus and both regulated branches need measured overvoltage protection. The exact regulator, fuse and clamp values wait for this measured circuit. Do not call this a released schematic.

Proposed Pico 2 pin allocation, to make sure of before you solder:

| Pico GPIO | Function |
| --- | --- |
| 0 / 1 | UART0 manual receiver or external command bridge |
| 2 / 3, 4 / 5 | Left and right quadrature encoders through level conversion |
| 6 / 7, 8 / 9 | Left PWM/direction, right PWM/direction |
| 10 | Both driver SLEEP inputs through kill/watchdog gating |
| 11 / 18 | Left / right active-low driver fault inputs |
| 12 / 13 / 14 / 15 | SPI1 MISO / chip-select / clock / MOSI |
| 16 | IMU data-ready interrupt |
| 17 | Servo transceiver direction |
| 19 | Deliberate arm input |
| 20 / 21 | UART1 servo TX / RX |
| 22 | Watchdog heartbeat; kill status handled by enable gate |
| 26 / 27 / 28 | Left current, right current, divided battery voltage |
| USB | Laptop commands and logs; never the hard kill path |

## Measured gates before this becomes a robot claim

1. Measure the total mass, the CoM and the pitch inertia. Use the same measured parameters in the simulator. Adjust the battery/frame mass position to keep the sprung fore/aft CoM in ±2 mm of the nominal balance line at pinned 30°. A near −4 mm offset exposed a limit in the grade-settle behavior. Do not accept that offset with a less strict test. Do a tire traction test on both intended floors. Inspect the full motor/bearing fit inside the 230 mm track.
2. Characterize **both** wheel channels at loaded battery minimum: 0.50 N·m short peak near 96 rpm, 0.15 N·m continuous, reversal response, voltage-to-torque response, deadband and gearbox lost motion. Keep the measured current/temperature traces. If the selected pair fails, reopen the motor decision with evidence. Do not increase the limits.
3. Demonstrate ≤6 ms sensor/estimator age and ≤10 ms effective drive lag under log load. These are simulation study limits, not datasheet promises. The firmware must allow for the estimator delay. A 25 ms delayed angle is not permitted.
4. Complete the [mobility and disturbance protocol](v1-proof-validation.md) with pinned legs before powered height adjustment. Fixed low/high simulated poses do not validate linkages in motion.
5. Do a test of the servo hold, the rail behavior and the measured pitch trim before ten powered height cycles. If the 9 V torque is not sufficient, keep the legs pinned and reopen the transmission/servo selection in the budget. Do not connect the servos directly to an unprotected full 3S pack.

## Carry forward to higher requirements

Keep a versioned command/telemetry contract: SI units, monotonic timestamps, sequence number, requested speed/yaw, measured attitude/rates, signed encoder counts, wheel current/voltage, leg feedback, control mode, saturation, sensor age and fault reason. A future Linux/vision computer sends bounded commands to the same MCU. The MCU keeps the balance, limits, watchdog and kill behavior.

V1 delivers the measured actuator maps, calibrated estimator, fault behavior, simulation regression cases and repeatable test fixture. V2 can add a single forward perception camera and companion compute after we allocate their power/mass and run these tests again. Larger steps, rough ground, side-shove recovery and stairs need new contact/leg authority and probably different mechanics and actuators. There is no promise that the proof chassis will scale to the stair climb.

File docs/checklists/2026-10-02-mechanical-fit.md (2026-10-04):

# First mechanical fit session — opened 2026-10-02

**Status: ready to start. No test results are recorded.** The user reports that the 30:1 metal gearmotor and the DRV8874 drivers arrived. The user also reports that the parts are 3D printed. The paid baseline is Pololu 4752 / 4035.

Do a check of the received labels and the total driver count. The servo arrival is not reported. This session checks the printed geometry and the packaging by hand, with all power disconnected. These checks do not need a controller or a servo.

Use the [living layout and dated session timeline](../../tools/living-drawings/mechanical-tests.html) during the session. Use it to inspect the spacer stack and to compare the poses. Use it to draft the measurements as the session happens.

If the prints match revision R01, use the [R01 assembly guide](../../cad/prints/v1-proof-r01/README.md#assemble-and-check-by-hand). Its generic slots, pivot holes and wheel disc do not give actuator mounts, bearing support or load capacity. Confirm the printed revision before you use its spacer layout.

## Setup and received parts

- Test date / operator:
- Printed filenames or revision / printer / material / settings / quantities:
- Motor label / quantity / measured mass:
- Driver label / received quantity (paid receipt records one):
- Fasteners / washers / spacers / actual stack dimensions:
- Photos and measurement notes:

## First session

1. **Inspect and measure.** Look for cracks, separated layers, warped plates and damaged holes. If the fit coupon is printed, measure it. Try the intended M4 hardware. Do not apply force. Measure both link center distances and both pivot separations. Do not scale the whole kit to correct a hole fit.
2. **Assemble the passive leg.** For R01, fit 2 mm spacers at both ends of the lower link. Fit 12 mm spacers at both ends of the upper link. Keep the fixed plate and the carrier behind both links. Select the bolt lengths against the actual stack. Retain the fasteners, but let the pivots move. Make sure that the bolt ends, heads and washers do not touch the other link.
3. **Support and sweep by hand.** Secure the fixed plate. Support the carrier. Make sure that the servo/belt is disconnected. Move the leg carefully through 15°, 30° and 45° rearward from the downward vertical. Check the intermediate positions. Approach each position from both directions. Stop if a part binds, rubs or cracks. Stop if hardware is loose. Record the cause before you change anything.
4. **Check the packaging with the received motor.** Measure the motor body, the shaft, the mount features and the cable exit. Hold the motor in the proposed location, or support it independently. Inspect the motor, hub, wheel and cable envelope during the full sweep. The optional 100 mm printed disc is a clearance reference, not a usable wheel. Do not load the provisional printed holes or the generic slots. Record the missing axle/bearing support and the missing mount details.
5. **Record repeatability.** If the first sweep is clear, make five slow hand sweeps. Then check the pivot retention and the print condition again. At neutral, carefully reverse the approach direction. Record the free play or the axle-position change. Do not apply a test payload. Save photos of the neutral pose and the closest clearances.

For the 110 mm / 40 mm parallelogram, measure the axle position relative to the lower body pivot. Rearward and downward are positive. The reference values below are model references, not measured results or fit tolerances.

| Leg angle | Reference rearward x | Reference downward y | Measured x / y | Minimum clearance / binding / play |
| --- | ---: | ---: | --- | --- |
| 15° | 28.47 mm | 106.25 mm | | |
| 30° | 55.00 mm | 95.26 mm | | |
| 45° | 77.78 mm | 77.78 mm | | |

| Item | Design reference | Measured result / disposition |
| --- | --- | --- |
| Lower / upper link centers | 110 mm each | |
| Fixed / carrier pivot spacing | 40 mm each | |
| R01 pivot holes / intended hardware | 4.5 mm nominal / M4 provisional | |
| R01 lower / upper spacers | 2 mm / 12 mm at both ends | |
| Motor mass, envelope, shaft and mount | Measure received hardware | |
| Wheel, hub, bearings and cable clearance | 100 mm nominal wheel envelope | |
| Five hand sweeps / neutral free play | Observe and record | |

## Outcome and next gate

- [ ] The printed revision and the dimensions are recorded.
- [ ] The actual fastener stack is retained. No part binds or collides.
- [ ] The full passive sweep and the closest clearances are recorded with photos.
- [ ] The motor/wheel packaging and the open mount/bearing details are recorded.
- [ ] The repeat sweeps are complete. The print condition and the free play are recorded.

- Fit issues / failed checks / changes needed:
- Evidence paths:
- Next bounded test:

This session can give passive fit observations only. Before a powered wheel test, detail a restrained motor mount and a wheel support. Then complete the [bench plan's power, current-limit, encoder and fault checks](../one-leg-bench.md#power-and-interfaces). Powered leg motion also needs the received servo, a supported transmission and a qualified fixture. R01 has no applied-load qualification, so a loaded test needs a reviewed load path and the later bench gates. If a stage is not done, keep it open in the [full session record](one-leg-bench-session.md).

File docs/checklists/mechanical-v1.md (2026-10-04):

# V1-PROOF mechanical and acceptance checklist

## P0 — inventory and layout

- [ ] Record reusable parts, exact variants and quantities in [inventory](../parts-on-hand.md).
- [ ] Quote the missing items. Keep the all-in total less than $1,000. Keep the repair allowance.
- [ ] Compare the mass allocations with the 2.5 kg target / 3.0 kg maximum.
- [ ] Make a mock-up of the full wheel/motor/bearing/battery envelopes, the body, the pivots and the cable sweep.
- [ ] Detail both the pinned structure and one reduced-servo parallelogram before you machine the parts.

## P1–P2 — two driven wheels, pinned legs

- [ ] Secure the wheels to supported axles. Route the wires. Fit the rest skids/catch fixture.
- [ ] Pin both legs at neutral. Measure the assembled CoM and the wheel/encoder polarity.
- [ ] Qualify wheel torque/reversal/thermal behavior at low operating voltage.
- [ ] Complete 60-second balance in 9/10 starts without support contact.
- [ ] Complete five forward/stop/reverse/turn sequences at 0.25 m/s.

## P3 — one then two powered legs

- [ ] Do a check of the bearing-supported driven pivots, 3:1 reductions, belt engagement, mechanical stops and lock pins.
- [ ] Hold 0.75 N·m at the mounted servo for 10 minutes at the lowest actual rail voltage. Stay in the documented thermal limits. Qualify a 1.0 N·m short transient separately.
- [ ] Measure backlash, friction and full swept clearances under load.
- [ ] Measure the CoM and the required pitch trim at the low/mid/high poses. Keep both wheels loaded.
- [ ] Add synchronized slow height motion. Complete ten low/high/low cycles with a measured body-height change of ≥25 mm and no support contact.

## P4 — full proof

- [ ] Run the fault tests in the fixture. Make sure that the rearm is deliberate.
- [ ] Run a ten-minute mixed session without resets, overloads or falls.
- [ ] Record the final mass, the actual spend with freight/tax/repairs, the videos and the logs.
- [ ] Close every [finish-line](../v1-proof.md#finish-line) criterion. Do not substitute calculated screens for physical tests.

## Revision B mobility gates

- [ ] Obey the [selected hardware and interface decisions](../v1-proof-hardware.md).
- [ ] Complete the [physical mobility/disturbance protocol](../v1-proof-validation.md). Include reverse travel, both arcs, both pivots, pulses and uneven fixtures.
- [ ] Record the measured CoM/inertia, motor response, current, latency, traction and backlash. Run the simulation again with those values.
- [ ] Retain the failures and the logs. Simulated passes do not close physical acceptance boxes.

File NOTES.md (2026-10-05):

# Working notes — V1-PROOF, updated 2026-10-05

The active objective is a useful, inexpensive proof robot. **Under $1,000. Reuse first. 2.5 kg target. Four actuators. Indoor mobility with bounded disturbance tests.** The previous stair work is [parked](docs/archive/stair-v1/README.md).

## Ready for review

- [x] Separate V1-PROOF model, requirements, cost/mass allocations and finish line.
- [x] Small four-actuator concept. The first build uses two driven wheels and pinned legs.
- [x] Conservative $900 budget that includes replacement allowances and reserves.
- [x] Preliminary 2D envelopes and reproducible geometry/load calculations.
- [x] Selected hardware baseline and physical mobility/disturbance protocol.
- [x] Pinned-leg 3D maneuver simulation, uncertainty sweep and saved challenge cases.
- [x] Previous plans preserved and legacy pages labeled.
- [x] Drivable [3D sandbox](tools/living-drawings/proof-sandbox.html) on the simulator of the study and the protocol fixtures, with size references. Leg-height motion there is a preview only.

## Next physical work

**2026-10-05 electrical print views:** EL-01 and EL-05 now use separate 11 x 17 inch landscape PDFs with 0.5 inch margins. The Electrical page includes a PDF view and a download link for each sheet. The five-sheet atlas uses the same paper size. The SVGs supply both the screen diagrams and the PDFs.

The [export procedure](cad/wiring/README.md) describes the update command and visual checks. A source or export change stops the site build until the PDFs match. The source audit remains Rev B. No physical test result changed.

**2026-10-04 writing standard:** all active text now obeys [Simplified Technical English](docs/writing-standard.md). Read `CLAUDE.md` and `tools/ste/SKILL.md` before you write. Run `python3 tools/ste/check_repo.py` before you finish. The gate is part of `npm run test:site`. The archive and the research notes keep their original text. No hardware status changed in this update.

**2026-10-03 Pico/IMU arrival:** one Pico 2 with yellow pre-soldered headers and one LSM6DSO IMU are received, untested. Start the [USB/LED bring-up checklist](docs/checklists/2026-10-03-pico-bringup.md). The October 2 Amazon order totals $30.58 and covers both received parts. The confirmation of the user supersedes the arrival estimate in the screenshot.

This sensor replaces the earlier LSM6DSOX choice, subject to qualification. Recorded spend is now **$173.70**, with **$726.30** remaining under the $900 plan. Item prices, shipping, tax and payment date remain unshown. No test pass is recorded.

**2026-10-02 mechanical timeline:** we added the [mechanical testing page](tools/living-drawings/mechanical-tests.html) with a movable side/end-view diagram, the R01 print render, eight evidence gates and shared dated history. Device session drafts record measurements, trial outcomes and evidence, with export/import and recoverable removal. [Recording workflow](docs/mechanical-testing.md). No physical test result is inferred from this page.

**2026-10-02 arrival and printing update:** the user reports the **30:1 metal gearmotor and DRV8874 drivers received**, and the **parts 3D printed**. The mechanical tests can start. Start the [first mechanical fit session](docs/checklists/2026-10-02-mechanical-fit.md): inspect and measure the prints, assemble the passive parallelogram, sweep 15–45° by hand, and dry-fit the motor/wheel envelope with all power disconnected. Confirm the printed revision/material and the total driver count.

ST3215 arrival, powered mounts, load capacity and electrical qualification remain open. No test pass is claimed. Recorded paid spend remains **$143.12**. This update supersedes the arrival/printing status in the dated September 29 notes below.

**2026-09-29 receipt update (supersedes missing-cost notes below):** [Paid receipts](docs/purchases.md) establish one Pololu 4752 gearmotor + one 4035 driver shipped ($88.34), and two ST3215 servos paid ($54.78). The total of **$143.12** includes shipping/tax. These models lock the actuator baseline, but the second wheel channel is still necessary. The website now explains [motor wiring](docs/v1-proof-hardware.md) and [Pico-based intelligence](docs/software.md). Firmware and physical qualification remain open.

**2026-09-29 print-kit update:** we drafted the [V1-PROOF R01 passive mockup](cad/prints/v1-proof-r01/README.md) for **Bambu X1C / PLA**, with eight STL part types and a Blender project. It keeps 110 mm link centers and 40 mm pivot spacing, and the M4 interfaces are provisional. Print and measure the fit coupon first, then inspect the passive linkage by hand. No physical print, fit, load or bench milestone is complete. Pololu 4752 gearmotors and ST3215 12 V servos remain ordered and not received.

**2026-09-29 update:** the user confirmed **Pololu 4752 gearmotors and ST3215 12 V servos are ordered for V1-PROOF**. Quantities and actual costs remain to record. RobStride is for the future full-size Hux. A bench supply is available with ratings still to confirm, and controller/driver/interface availability remains open. Start the [single-leg bench plan](docs/one-leg-bench.md) while you wait for the delivery.

Its [1:1 template](cad/layouts/one-leg-bench-template.svg) supports a passive mockup now. Hardware-specific machine work follows the receipt/label checks. Supported leg motion can precede balance. The pinned-leg-first sequence below governs the robot in free motion.

1. Inspect and measure the received **Pololu 4752 gearmotor and DRV8874 drivers** and the printed parts. Confirm the total driver count against the [paid-order ledger](docs/purchases.md). **$173.70 recorded spend** includes the new controller/IMU order. Examine the received Pico 2 over USB. Confirm the LSM6DSO IMU and ST3215 servo arrivals and check the labels when they are available. Confirm the bench-supply rating, servo interface, radio/transmitter, battery/charger, wheels and stock. The second wheel motor remains to buy. Another driver depends on the inventory count.
2. Make a scrap/cardboard mockup at the proposed 28–31 cm height. Weigh the pile. Make sure that two gearmotors, bearings, wheels, wires and the battery fit.
3. Qualify one wheel channel and controller in a supported fixture. Make sure that encoder sign, reversal, hardware current limit, kill, watchdog and available torque at speed are correct.
4. Build the second wheel channel and pin both legs at neutral. Tune conventional two-wheel balance and slow manual drive.
5. Do a bench test of one small servo with its 3:1 reduction and a loaded leg. Then add both leg channels slowly. Keep both wheels planted during this step.
6. Run the expanded [mobility and disturbance trials](docs/v1-proof-validation.md), then the height/duty/fault finish line. Replace the simulation assumptions with measured data and rerun the matrix.

No stair analysis, perception hardware or detailed cosmetic head work is on the critical path. The 2026-09-28 design revision placed no orders. The subsequent purchase report of the user is recorded above. Source/model tests cannot check physical balance.

## Latest simulation outcome

Final broad sweep: **388/391** numerical passes. All forward/reverse, left/right arcs and both in-place turns pass **17/17 configurations**. Three settling failures remain at seed 102 with nearly −4 mm fore/aft CoM error. All six separate ±2 mm CoM-placement checks pass. Keep the ±2 mm assembly requirement and every failed result.

The nominal suite is 23/23. The finer-timestep checks pass. Large shoves, 20 mm obstacles and excessive latency are outside the supported study envelope. [Full evidence](docs/v1-proof-simulation.md).

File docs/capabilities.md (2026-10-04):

> **V1-PROOF update — 2026-09-28:** the shop capabilities below remain useful. References to carbon spars, custom in-wheel hubs and stair geometry are historical; suitable scrap/COTS construction is now preferred. [Active mechanical plan](mechanical.md).

# Shop capabilities

**Status:** the user, 2026-09-20. **Docs only.** These are **tools the user can use**, not parts on hand and not a buy list. **No new spend.**

Hardware fabrication is **intentional and welcome**. The user can mill, turn, bend, cut, solder, and weld Hux parts — not only 3D print them. The inventory of owned / ordered *parts* stays on [`parts-on-hand.md`](parts-on-hand.md). Mechanical intent: [`mechanical.md`](mechanical.md).

## Metal / machine shop

| Capability | What it is for (intent) | Notes |
| --- | --- | --- |
| Mill | Plates, flats, pockets, hub features, mounts | Natural home for an **in-wheel BLDC hub** (bore, register, bolt circle). |
| Lathe | Round work: hubs, shafts, spacers, registers | Pair with the mill for the first custom wheel hub. |
| Metal bender | Brackets, light formed sheet | Prefer COTS stock as the blank. |
| Metal brake | Folds / flanges in sheet | Same — form stock; do not invent a sheet SKU. |
| Bandsaw | Cut stock to length | Carbon rod / tube / bar / plate. **Do not mill a spar that a tube already is.** **Carbon dust:** respirator + **wet cut** (Tazer lesson). Do not dry-saw a cloud of carbon into the mill. |

## Join / proto

| Capability | What it is for (intent) | Notes |
| --- | --- | --- |
| Soldering | Harness, proto, rework | Bench electronics. Not a reason to invent a Hux PCB. |
| Welding | Steel / weldable stock joints | Welcome when a weld is the honest joint. Not a sealed mono-body excuse. |
| Breadboards | Electronics proto | Fine for blink / bind / driver bring-up. Not a flight stack. |

## How this sits next to structure rules

- **The user can machine, bend, or weld custom parts**, or 3D print them. Do not treat “printable” as the only permitted custom part.
- The **in-wheel BLDC hub** (donor Zantle rubber + custom hub) is a **natural lathe / mill part**. That is the intended first shop job, not a stretch goal.
- Still **prefer COTS structure** (carbon rod / tube, metal stock, fasteners) where it fits. Do not mill a spar that a tube already is (R19 / R34).
- **Carbon-fiber dust is not a toy.** Use a respirator and a wet cut when the bandsaw cuts tube. Refer to [`research/tazer-lessons.md`](research/tazer-lessons.md).
- **Draft-friendly print still for plastics** — joints, clamps, brackets, fairings. Print is welcome. It is not the only shop.

Do not add a list of tools to buy here. Do not recommend machines, inserts, or stock SKUs. When a real custom part exists, put the CAD / 2D files in [`../cad/`](../cad/) and note it in [`../NOTES.md`](../NOTES.md).

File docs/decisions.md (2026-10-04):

# Decisions

This is the dated log of the decisions of the user for Hux, in the order that they landed on `main`. The newest intent **supersedes** older language on the same topic.

**Standing rule (the user):** merge docs PRs promptly. Keep `main` current. **Log each merge here.** Do not leave docs PRs that conflict open against a stale `main`.

The source of truth is this repo (`nova-centauri/hux-robot`). Docs only. **No spend.** No SKU locks beyond the locks that are already decided below.

## Current governing decisions — V1-PROOF, updated 2026-10-04

The user extended V1-PROOF to dependable forward/reverse traversal, left/right turns, rotation in place, bounded pushes/uneven terrain and concrete component decisions. This extends the proof scope but keeps its cost, mass and four-axis limits. The earlier dated entries remain history.

| Topic | Current decision |
| --- | --- |
| Active model | V1-PROOF is current; V0-GENESIS names the old planning model (historically STAIR-V1); a third version follows the proof, with scope/name open |
| Cost / mass | Strictly < $1,000; **$900** allocation including $225 reserves; 2.5 kg target / 3.0 kg maximum |
| Actuators | **2 × Pololu 4752 wheels + 2 × ST3215 12 V variant legs through 3:1 belts**; first mobility with pinned 30° legs |
| Drivers | **2 × Pololu 4035 DRV8874**, configured current limiting, sleep/kill/watchdog, PH/EN and fixed-off-time regulation |
| Control / sensing | **Pico 2 + SparkFun LSM6DSO received, SPI planned**, encoder/current/fault/battery feedback; USB, sensor and timing qualification open |
| Power | 3S approximately 2.2 Ah; **9 V servo / 5 V logic branches**; actual pack, regulators and protection require measured circuit qualification |
| Cameras | **Zero onboard in V1**; existing external video for trials; perception is a later version gate |
| Motion | 0.25 m/s cruise, 0.15 m/s uneven fixtures, 0.4 rad/s arc / 0.6 rad/s pivot; 0.5 m/s not yet qualified |
| Disturbances | Qualification targets: 0.8 N·s longitudinal / 0.4 N·s lateral at 0.20 m, 50/200 ms pulses; 3° grades/cross-slopes, 5 mm smooth bump, 3 mm seam |
| Evidence | Pinned-leg 3D closed-loop simulation with seed/parameter sweep and failure cases; physical validation and powered-leg dynamics remain open |
| Next versions | Carry measured actuator/sensor models, telemetry, fault behavior and tests forward; no promised stair upgrade of this chassis |
| Orders / publication | **Motor/drivers, Pico and LSM6DSO received; 2 × ST3215 ordered; $173.70 recorded spend**. Second wheel motor still required; total delivered driver count pending. User confirms servo 12 V variant. New order charge breakdown is unshown. Publish through the existing CI/CD when authorized and verify live pages. |
| Writing standard | **All active text obeys ASD-STE100 Simplified Technical English** (2026-10-04); `python3 tools/ste/check_repo.py` is a build gate in `npm run test:site`; `docs/archive/`, `docs/research/` and the V0-GENESIS pages stay historical |

Refer to [hardware decisions](v1-proof-hardware.md), [simulation evidence](v1-proof-simulation.md), [physical acceptance](v1-proof-validation.md), [PF requirements](requirements.md) and [numerical source](../tools/v1-proof/model.json). The hardware selections are the current engineering baseline. They remain subject to explicit bench rejection criteria and budget limits.

---

## Log

### 2026-10-04 — Simplified Technical English becomes the writing standard

The user asked us to include the [simplified-technical-english skill](https://github.com/0xpili/simplified-technical-english) in the notes and to enforce it in all text. We vendored the skill in `tools/ste/` and wrote the [writing standard](writing-standard.md). A root `CLAUDE.md` tells each future session to read the skill before it writes. The gate `python3 tools/ste/check_repo.py` checks the active Markdown, the V1-PROOF plan data, the V1-PROOF page text and the text constants of `build_site.py`. `npm run test:site` fails when the gate finds an error.

We rewrote 52 active files from 846 structural errors to zero. The archive, the research notes and the V0-GENESIS pages stay in their original text, labeled as historical. An independent review compared every number, date, price, part identifier, link target and checkbox before and after the rewrite. It found no changed fact. The names table in the standard fixes one name for each part. The 869-word vocabulary check stays advisory, because robotics technical names are not in the ASD list.

### 2026-10-03 — Pico and IMU received; shopping list reconciled

The user confirms that the Pico 2 and the LSM6DSO IMU are both here. Mark the existing controller/IMU order as received. Its **$30.58** is already counted, so the recorded spend remains **$173.70**, with **$726.30** remaining under the $900 plan. Keep the individual costs and charges as unknown. No more purchases and no test are reported.

Publish the homepage spend ledger and the [remaining shopping list](bom.md#remaining-shopping-list). One more wheel motor is necessary, and you must confirm the actual driver count before you buy another driver. Two ST3215 servos are already paid, and their arrival is not reported. The remaining interfaces, wheels/transmissions, controls, battery/charging, protected power, harness, assembly hardware and fixture materials need inventory or purchase confirmation. Keep the $125 repair reserve. [Order evidence](purchases.md) · [Inventory](parts-on-hand.md).

### 2026-10-03 — Pico received; ordered LSM6DSO replaces the reference IMU

The user reports the receipt of the Pico 2 and supplies a screenshot of an October 2 Amazon order with a total of **$30.58**. The screenshot shows a Pico 2 with yellow pre-soldered headers, delivered, and an **LSM6DSO IMU** (SparkFun Qwiic) with arrival tomorrow. We recorded this on October 3, and the IMU estimate is October 4. The receipt of the IMU remains unconfirmed. Add this order one time to the recorded spend: **$173.70 total, $726.30 remaining** under the $900 plan.

Leave the individual prices, shipping, tax and payment date unknown. Do not allocate the combined total to the items. Private order/account details and the unredacted screenshot stay outside the public repo.

Use the ordered LSM6DSO IMU as the sensor baseline. It explicitly replaces the earlier Adafruit LSM6DSOX selection. Its documented primary SPI, interrupt outputs and 3.3 V operation support the proposed interface. This is an engineering fit assessment, not a measured latency or balance result. Make sure that the pads/jumpers of the received breakout are correct, and implement the LSM6DSO initialization. Keep the existing ±4 g / ±500°/s / 833 Hz sensor targets and the 500 Hz control target, all subject to qualification.

Open the [Pico USB/LED checklist](checklists/2026-10-03-pico-bringup.md) with the official Raspberry Pi example UF2s. No embedded Hux firmware, no board test result and no physical milestone pass is reported. Mechanical fit work can continue in parallel with this board-only check. [Inventory](parts-on-hand.md) · [Order evidence](purchases.md) · [Hardware](v1-proof-hardware.md).

### 2026-09-29 — Paid parts lock the proof design; publish wiring and intelligence

The user requested the incoming Pololu order and the actual spend on the budget page. The user also requested an explanation of the motor connections and the V1-PROOF intelligence, and a current published living page. A read-only reconciliation of the receipts gives **one Pololu 4752 gearmotor + one DRV8874 driver shipped for $88.34**. It also gives **two ST3215 servos paid for $54.78**. Both amounts include shipping/tax.

**Total paid: $143.12**, and **$756.88 remains in the $900 planning ceiling**. That remainder must cover future purchases and reserves.

Refer to the [public-safe purchase evidence](purchases.md). The earlier notes below about missing quantities/costs are historical.

Lock the purchased motor, driver and servo models as the V1-PROOF bench baseline. The robot still needs two wheel channels, but only one is purchased. The user confirms the servo 12 V variant, and the receipt/label check remains an arrival gate. Keep the 100 mm wheels, the 3:1 leg reductions, the 110 mm links and the pinned-leg-first free-robot sequence. Hardware fit, loaded performance and control implementation remain open. A substitution needs an explicit recorded decision with bench evidence.

The six-wire connector of the wheel motor splits into driver power and encoder feedback through a harness. The Pico 2 controls the DRV8874 driver, and the encoder A/B signals need level conversion. The V1 intelligence is timestamped IMU/encoder estimation, conventional balance control, bounded human commands, slower height control and local fault handling. The existing simulation is host software. The embedded firmware and the physical balance are not yet implemented or proven. [Hardware](v1-proof-hardware.md) · [Software](software.md).

**Publication:** the host served raw source files, so the generated document pages were not available. Infrastructure [PR #27](https://github.com/nova-centauri/vps-1/pull/27) and [PR #28](https://github.com/nova-centauri/vps-1/pull/28) passed the required CI and merged in two stages. The host now builds validated releases, promotes the site atomically, checks the document routes and shows its deployed Hux revision at `/deployment.json`. We checked the baseline rendered budget and guides before we pushed this content update. The user requested this repo update and the live CI/CD validation, and authorized publication to `main`.

**Validation:** all 42 site/data/notebook/budget tests pass. The active model and simulation checks pass, and the generated site has no broken local links. This publication completes no physical milestone.

### 2026-09-29 — Versioned living build plan

The user named the old planning model **V0-GENESIS** and confirmed **V1-PROOF** again as the current build. A third version follows V1-PROOF. The third version remains without a name and without a scope. Keep the original stair research file names, dates and historical terminology under the V0-GENESIS archive. Their requirements do not govern the proof.

The website now has separate version routes and a source-backed WIP plan for orders, the single-leg bench exercise, milestone criteria and dated updates. Render the source Markdown into navigable HTML pages. Browser bench notes remain local drafts until we review them and record them in the repository. Ordered quantities, paid costs and delivery remain open. The publication of a page completes no physical test.

**Publication:** the user requested “push to main,” and this authorized the direct push of this website and planning update to `main`. All 28 site checks and the active model/simulation checks pass. The generated site contains 65 readable guides with no broken local links or section anchors. The pre-existing local vendor CAD and the downloaded meshes remain outside the commit and the published bundle. The live hosting deployment is separate and remains unverified.

### 2026-09-29 — V1-PROOF actuator orders confirmed; single-leg bench preparation

The user confirmed that the ordered actuators are **Pololu 4752 gearmotors and ST3215 12 V servos**, for the current **V1-PROOF test version**. RobStride actuators are more expensive, and their purpose is the future full-size Hux. This clarification does not establish a RobStride purchase. The older vendor-CAD purchase text that conflicts does not govern V1-PROOF.

Prepare a supported single-leg bench before the parts arrive. Use the current 110 mm parallel-link geometry. This bench can come before the two-wheel balance. Pinned legs remain the first free-robot mobility configuration. A bench supply is available, but its model/ratings are still to record. The actuator quantities, actual costs, drivers, controller and servo interface remain to record.

This entry claims no physical test and no firmware implementation. Refer to the [bench plan](one-leg-bench.md) and the [inventory](parts-on-hand.md).

**Publication:** the user requested “Commit and push this to main,” and this authorized the direct push of this change to `main`. The change holds the bench plan, the printable geometry template, the session record and the confirmed actuator inventory. Seven model checks and the generated-output consistency checks pass. The pre-existing untracked vendor CAD and the downloaded meshes are outside this change.

### 2026-09-20 — #1 scaffold (merged)

Initialize the Hux wheeled-biped docs scaffold and requirements. The SoT is this GitHub repo. The north star is to climb / descend **~9.5″** residential stairs one wheeled leg at a time. Empty `cad/`, `firmware/`, `software/`. MIT license. No spend, and the FC is not locked.

### 2026-09-20 — #2 XRobots research (merged)

Research-first study packet: [XRobots shortlist](research/xrobots.md), [study plan](research/study-plan.md) Phases A–D. Watch / extract before any print. Do not vendor the XRobots trees. RobotX is GPL3 — do not relicense Hux (MIT) without the user. The printable wheel-leg is **Phase D**.

### 2026-09-20 — #3 Roadrunner + FrRonconi inspiration (merged)

The X-share inspirations of the user: [RAI Roadrunner](research/roadrunner.md) (lab RL wheeled biped — proof that the capability exists, not a Hux stack) and the [FrRonconi student two-leg/wheel balancer](research/inspiration.md) (maker-scale style). Watch the clips. Do not build from the clips.

### 2026-09-20 — #4 electric / 4S / wheel-actuator intent (merged)

**Electric-only** powertrain (R10). The battery preference is the **4S LiPo** class (~14.8 V / ~16.8 V) — not a pack SKU (R11). The hip + knee actuators are **TBD**, class research only (R12). The wheels are **~4–6″** thin rubber. **~6″** was the working hypothesis at this date (R13). Later notes prefer **5″** and put **in-wheel BLDC FOC** on the rim.

### 2026-09-20 — #5 modes (consolidated here)

Four **manual** control modes **before** autonomy (R14):

1. **`PARKED`** — safe idle / failsafe. No balance loop drives the wheels.
2. **`TWO_WHEEL`** — both wheels active. Bipedal teleop.
3. **`LEFT_ONLY`** — balance / drive on the left planted wheel. The right leg is free.
4. **`RIGHT_ONLY`** — the mirror of `LEFT_ONLY`.

The pilot selects the mode with the **TBS Nano** (probably in the aux / flight-modes style). The Wi‑Fi telemetry reports the active mode. A mode change does not lift, plant, or follow a path.

### 2026-09-20 — #6 CoG / hip-roll / reuse-control (consolidated here)

The V1 overall width is **~10″** (R15). One-leg balance is a **full loop** (R17): the hip roll keeps the weight over the planted wheel **and** that wheel drives fore/aft (inverted-pendulum pitch). **Reuse existing control** — do not write a new Hux balance stack for V1 (R18). Pointers: XRobots TallBalancer / SonicRobot / RobotX, Hattori, Mini-Cheetah-style stacks, FC attitude loops, ODrive / FOC torque modes.

Hip roll was "TBD if mandatory for V1" in this packet. **#10 supersedes that soft decision:** hip roll is **in V1**.

### 2026-09-20 — #7 fabrication / 2D-before-3D (consolidated here)

- **R19** — Prefer cheap **COTS** stock for the primary structure (carbon rods / tubes, metal stock, fasteners). The printed parts are joints / hubs / brackets.
- **R20** — Custom parts are **draft-friendly** (print now, mold later).
- **R21** — **Wire openings and ports** through the links and the body.
- **R22** — **Serviceable V1**: the fasteners, pack, FC and actuators are replaceable modules.
- **R23** — **Several 2D sketch layouts before any Blender / 3D CAD.** This is a hard process gate.

### 2026-09-20 — #8 mass / wheel motors (consolidated here; mass hardness superseded)

Size the wheel motors for **reaction speed / torque bandwidth** (balance), not for maximum continuous power (R25). Candidate *classes*: a light gimbal BLDC ~2208–4108 + FOC + encoder, or a mid small-outrunner + reduction if necessary. Avoid SonicRobot-class 63xx / hoverboard hubs.

The original **under 6 lb** / aspirational **4–5 lb** target (R24) is kept as a **historical preference only**. **#15 supersedes** any hard mass ceiling: the budget is **soft / blown**.

### 2026-09-20 — #9 leg actuators by axis (consolidated here)

The jobs are different — do not force one actuator type on every axis (R26). The trade study is in [`research/actuators-legs.md`](research/actuators-legs.md).

| Axis | Job | Class lean (later refined) |
| --- | --- | --- |
| Hip roll | Highest bandwidth, continuous small corrections, prefer backdrivable | Dynamic FOC / QDD / fast servo — **locked in V1 by #10** |
| Hip swing | Position + speed for the step cycle | **Servo vs stepper+belt TBD** (#14) |
| Knee | Highest gravity + step torque for ~9.5″ | **Servo vs stepper+belt TBD** (#14); springs / linkage still recommended |

### 2026-09-20 — #10 V1 actuator baseline + 8-axis I/O + hip roll in V1 (consolidated here; swing/knee lock lifted)

**Hip roll is IN V1** (R16 / R27): dynamic FOC BLDC / small QDD / fast bus servo. This is experimental — it can fail to work as we hope. Still ship the joint and `LEFT_ONLY` / `RIGHT_ONLY`. **Not a stepper. Not V2.**

This packet also locked the knee + hip swing to **stepper + belt/gear**. **#14 lifts that lock.** This is what remains:

- The wheels stay **brushless FOC** (R6).
- **8-axis I/O** (R29) is the architecture **if** the pose joints are steppers: 2 wheel BLDC + 4 steppers + 2 hip-roll dynamic.
- **The FC does not drive the stepper coils.** TMC-class / multi-axis driver board(s) go between the host and the motors. Preferred: FC = IMU + wheel FOC (+ hip-roll if PWM/CAN). **Pi or dedicated stepper controller** = 4× step/dir.
- Drone firmware as a stepper host is a V1 **anti-pattern**.

### 2026-09-20 — #11 electronics-minimum (consolidated here)

The minimum electronics plan is [`electronics-minimum.md`](electronics-minimum.md). It has a text block diagram, part *classes* (not SKUs) and a phased assembly order **P0–P5**. The FC stays TBD. No spend.

### 2026-09-20 — #12 mechanical layout (consolidated here)

- **R30** — The wheel drive is a **BLDC at the wheel** (hub / coaxial), not remote from the hip.
- **R31** — A **kV match** is a sizing *goal* (4S + diameter + balance bandwidth). No invented number.
- **R32** — If the pose joints are steppers, mount them **high** (above the knee), with **belts** to the pivots.
- **R33** — If belts: **one inside, one outside**. Integrate the toothed pulley into the printed custom part where it is draft-friendly.

Hip roll stays the V1 **dynamic** actuator. The placement is TBD. Do not lower the CoG with heavy roll actuators if you can avoid it.

### 2026-09-20 — #13 parts-on-hand + shop (consolidated here)

The inventory is [`parts-on-hand.md`](parts-on-hand.md). The shop tools (not parts) are in [`capabilities.md`](capabilities.md).

- **Zantle 5″** walker wheels are ordered (ASIN B0D534PDRT). **It is OK to cut them apart** — they are disposable donor rubber, not a part to keep.
- The soft preference for the wheel diameter moves to **5″** (still in the 4–6″ band).
- Shop: mill, lathe, metal bender, metal brake, bandsaw, soldering, welding, breadboards. Hardware fabrication is intentional.

### 2026-09-20 — #14 Serra / Build Some Stuff + servo vs stepper TBD + 2× plant + 4S step-down (consolidated here)

Copy the **packaging** of [Kelton Serra / Build Some Stuff](research/inspiration.md), not the files: in-wheel BLDC + encoder. The jointed legs keep the CoG over the contact as the height changes. Serviceable modular prints. Wheel-under-CoG correction geometry.

- **R12 lifted:** the knee / hip swing are **servo vs stepper+belt TBD**. No preference either way. The 40 kg-class servos of Serra are a data point, not a Hux SKU.
- **R36:** the plant-side knee / hip / hip roll see approximately **~2×** the two-wheel stance. Size them for that case.
- **R11 addendum:** keep **4S**. Add a **controlled step-down** (BEC / regulator *class*) to the 5 V / 6 V / 7.4 V pose or logic rails. Then the wheel FOC spikes do not brown out the planted joints.

### 2026-09-21 — #15 carbon tubes + ~24″ height + soft mass (consolidated here)

- **R34** — The primary **upper + lower leg spars** are **carbon fiber tubes**. Printed / machined **end fittings** only.
- **R35** — The V1 height is up to **~24″ at full extension**. The width stays **~10″**. Hux must still reach **~9.5″** with margin.
- **R24** — The mass budget is **explicitly blown / soft**. Capability and packaging win over the old 4–5 lb / under 6 lb numbers. Those numbers stay as a historical preference, **not a kill-switch**.
- Longer tubes → longer belt runs if a belt is the reducer. The joint actuators are at the hip / knee with the tube between them.
- **GIM8108-class** is noted as a knee / swing *candidate* (not ordered, not locked). This agrees with the open class of #14.

### 2026-09-21 — consolidation PR (this file)

The open PRs **#5–#15** conflicted with each other and with `main` (which already had #1–#4). The unique content is merged here. **The latest intent wins** on actuators and mass. After this lands, close #5–#15 as obsolete.

### 2026-09-21 — Tazer lessons (folded into consolidation)

The user shared [Tazer — My Robot almost got me Kicked out of Uni](https://www.youtube.com/watch?v=gqnW9qBCHnM): **learn a lot from the mistakes of this person.** The note is [`research/tazer-lessons.md`](research/tazer-lessons.md).

This does **not** change the locks, but it reinforces these points: the GIM8108-class is a live *candidate* (still not ordered). Carbon tubes are confirmed. 4S stays preferred (lighter than his ~48 V), but FOC stalls still need a real power bus, not a logic PCB. Start with simple PID / existing control (R18), not LQR on a bad model. Rubber, not TPU, carbon-dust PPE, and serviceability + software torque limits later.

### 2026-09-21 — #17 Stompy CAD→sim→real

The user asked for an analysis of [Stompy](https://www.youtube.com/watch?v=gEjg179fvmc) (Kayden Knapik — a one-week build of an RL walking biped), especially the simulations and the match of CAD to reality. The note is [`research/stompy-sim2real.md`](research/stompy-sim2real.md). It is indexed from [`research/inspiration.md`](research/inspiration.md), [`research/study-plan.md`](research/study-plan.md), and [`research/README.md`](research/README.md).

This does **not** change the locks. Walking ≠ Hux wheeled balance, but still copy these: the fixture / home pose, measure-vs-CAD, the tether, default angles in CAD+firmware, and a later CAD→model lockstep for geometry / stairs. **Do not make RL walking a requirement for Hux V1.** Keep **reuse simple balance control** (R18). Sim is not a day-one wheel-balance task. No spend, and no Jetson / Robstride / mjlab lock.

### 2026-09-21 — #18 Diablo wheeled-leg research

The user shared the [Diablo review of ETA Prime](https://www.youtube.com/watch?v=S5PoZ8aNwvs) plus the paper [arXiv:2407.21500](https://ar5iv.labs.arxiv.org/html/2407.21500) (Direct Drive Tech / DDTRobot commercial self-balancing wheeled-leg). The note is [`research/diablo.md`](research/diablo.md). It is indexed from [`research/inspiration.md`](research/inspiration.md), [`research/study-plan.md`](research/study-plan.md), and [`research/README.md`](research/README.md). The shop / SDK are cited only.

This does **not** change the locks. Copy these: the split brain (Pi vs motor board), DD/QDD as a *class* for high-bandwidth joints, **LQR/PID before RL**, height modes as states, aux contact later, payload vs height. **Do not buy Diablo.** Do not scale Hux to ~22 kg, and do not add head tilt / cargo / creep rollers for V1. Keep **reuse simple balance** (R18), and the hardware stays **TBD**. No spend, and no M1502D / ROS2 / Pi4-as-FC lock.

### 2026-09-21 — leg geometry + wheel contact

The user asked for a plan review and new leg math. The ordered walker wheels are not a sufficient foot. The user thinks about a small spoked bike tire with real rubber. Carpet and interior floors can wait.

The study is [`research/leg-geometry.md`](research/leg-geometry.md). **No spend. No tire SKU. Spokes are not locked.**

- **R13 updated.** The **4–6″ / 5″ preferred** contact plan is dropped. Zantle stays a disposable **bench donor**. The working draw is **~8″ OD**, **~1–1.25″ wide**, real rubber, torsionally stiff, until we measure a real tread. A **12–16″** kids bike wheel fails the tread, the **~10″** width, or the reaction-speed trade.
- Hip over the wheel: the knee gravity is the poke (a few N·m). A spring cancels the two-leg share. The hip roll sees the large moment when the other wheel unloads (`m g ×` half-track, ~6.5 N·m at 6 kg on the draw).
- The tubes stay stiff (bending above ~40 Hz). The compliance lives in the spring and in the radial tire compliance.
- The old **~0.8 N·m** wheel figure is historical (2 kg). The wheel target on the 8″ draw is approximately **3–4 N·m peak**. Not a SKU.

### 2026-09-21 — wheel settled at 6″

The user: the wheel must fit easily on one stair, so that the robot can pivot and put the raised wheel on the next step. Settle the diameter early.

The study update is [`research/leg-geometry.md`](research/leg-geometry.md). **No spend. No tire SKU.**

- **The design step is 9.5″ rise × 9.5″ going**, nosing to nosing. The going is the same as the riser already in R3. A deeper measured tread is spare margin, not a reason to make the wheel larger. Open this again only if a measured going is less than ~9″.
- **R13 is settled at 6″ overall diameter** (5.75–6.25″ still counts), width ~1–1.25″, real rubber, torsionally stiff. The whole tire sits between the nosing planes with approximately **±1.75″** of balance roll, and approximately **2.5″** of air under a 1″ soffit.
- The **~8″ working draw is withdrawn.** On a 9.5″ going it leaves approximately ±0.75″ of roll. A 12″ kids wheel does not enter the slot.
- The leg draw follows: **7.5″ + 7.5″** tubes, **6″** of body above the hip. The wheel peak is approximately **3 N·m** on the 6 kg example. Not a motor SKU.

### 2026-09-21 — first buy

The user asked if a BOM existed and said that he wants parts to arrive. There was no buy list. [`bom.md`](bom.md) is that list.

Spend is open **only** for 3× **6×1.25** ribbed pneumatic tires, 3× tubes that match, and 2× **1 m** carbon tube (**16 mm OD**, 12–14 mm ID). Motors, GIM8108, drivers, and another FC stay unauthorized. Do not order Zantle, the on-hand FC pile, TBS Nano, ESP32, or the Pi again.

### 2026-09-21 — knee to the rear, face, cameras

On the living drawings, the user wants the **knee behind** the hip. The poke stays approximately **2.9″** at the 92% stance. The page also has the rough motor bulk (not a buy) and seven cameras (front stereo pair plus back, sides, top, bottom). It also has a small front display for preset faces, and an RGB in each eye socket. The lit socket is the eye. None of the face or camera parts are authorized for purchase.

### 2026-09-21 — 14″ wide, BOM prices

The overall width moves from **~10″** to **~14″** (R15). The head stays a narrower unit, approximately **7″** on the drawing.
The wheels and legs are outside the head.
The track is approximately **12.75″** with a 1.25″ tire, so the one-leg moment at 6 kg is approximately **9.5 N·m**.

[`bom.md`](bom.md) now has store links, line prices, and totals. **$89.41** is the authorized order. The working total of approximately **$1,140** includes class estimates for parts that are not selected and not authorized.

### 2026-09-22 — stair climb dynamics in the living drawings

The user asked for judgment calls on gravity, weight, CoM, momentum, inertia and motion in the stair animation, and for improvements to the tool. The climb in `tools/living-drawings/kin.js` now models these: the front wheel rolls back under the mass during the flight and catches the remainder after the crest. It also models the joint torques for both legs, the lateral sway and roll moment (with a front view), real-time playback, and design knobs that rebuild the step.

The findings are in [`research/stair-climb-dynamics.md`](research/stair-climb-dynamics.md). On the settled geometry, the step-to gait is a **±6% precision throw**, because the rear leg leaves the mass 2.7″ behind the front contact.
A **forward landing error of ½″ makes the step impossible**, so aim at the rear of the slot.
A body CoM **1–2″ ahead of the hip axes** is the cheapest correction and makes the step routine.
When Hux stands up over the front wheel, the knee holds **~10.6 N·m**, not the 4.4 N·m stance figure. **Nothing is locked.** No spend, and the lump masses are still a picture, not a weighed robot.
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

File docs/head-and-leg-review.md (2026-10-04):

> **PARKED STAIR-V1 — 2026-09-28.** This is historical research, not an active requirement, BOM or build gate. [V1-PROOF](v1-proof.md) governs current work.

# Head and leg engineering review — 2026-09-28

**Disposition:** retain the one-step objective, reopen the leg architecture, and do not buy the actuator set yet. The old robot has no demonstrated controlled single-support phase and no feasible full spatial stair trajectory. A 0.2-second floor hop does not prove either. Today the user told us to fix the legs to justify the actuator cost, or to explicitly drop stairs. This review does **not** silently drop stairs.

**The user purchased no Hux components.** Earlier “already bought,” “ordered,” and “on order” claims are superseded. Vendor geometry is a design reference, not inventory.

The preferred *research direction* is a finite-width wheel support with active ankle roll and also hip roll. It gives the missing lateral ground moment. It is **not yet a buildable, validated replacement**. The compact version still fails reach.
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

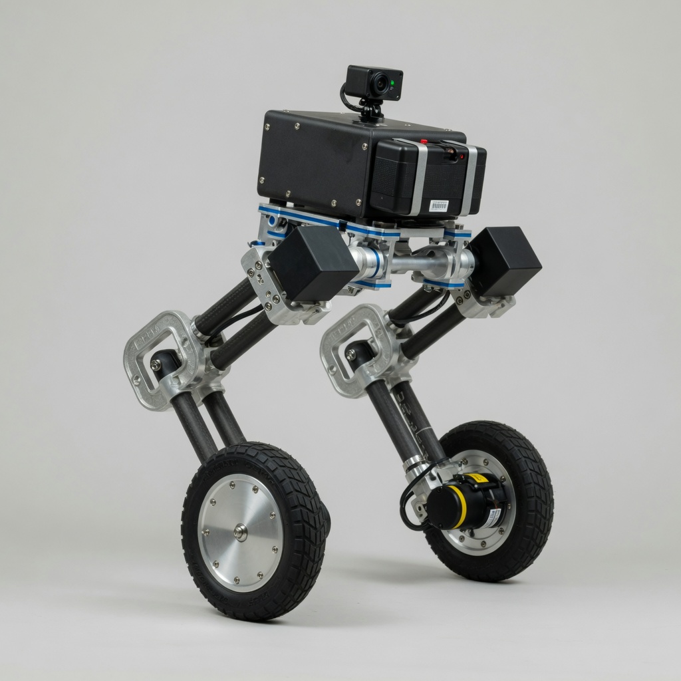
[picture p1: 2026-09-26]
art/concepts/hux-standing.jpg

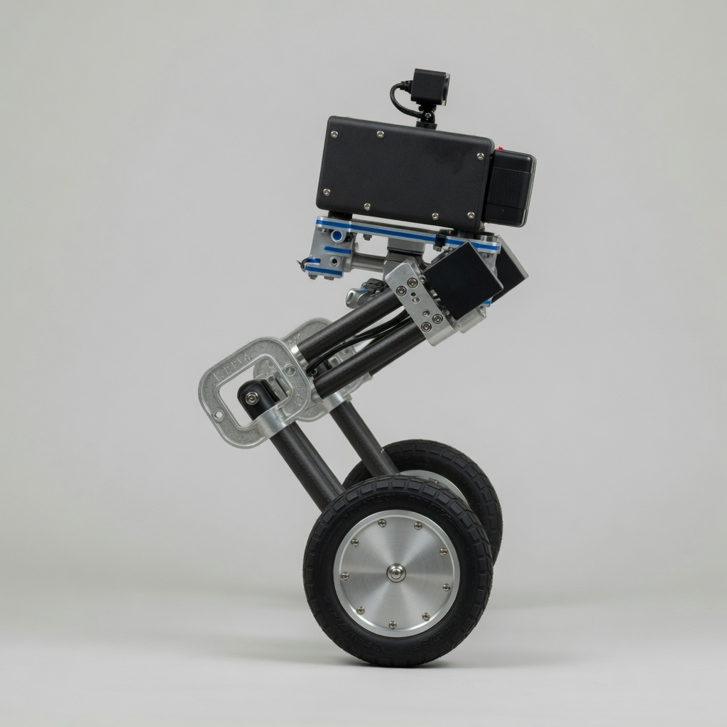
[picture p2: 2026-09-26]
art/concepts/hux-side.jpg

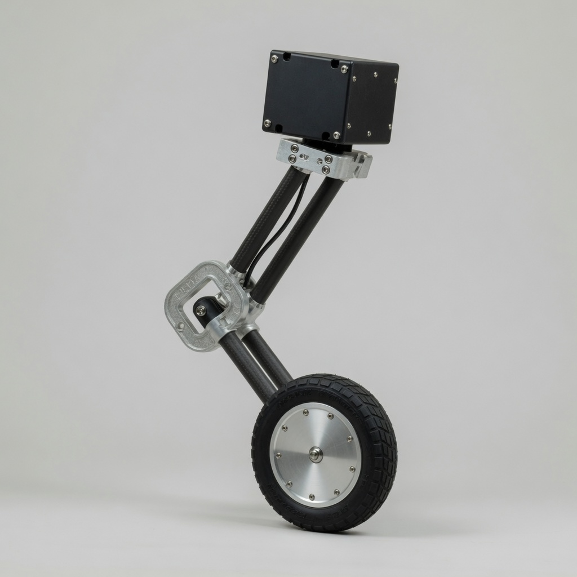
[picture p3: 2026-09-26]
art/concepts/leg.jpg

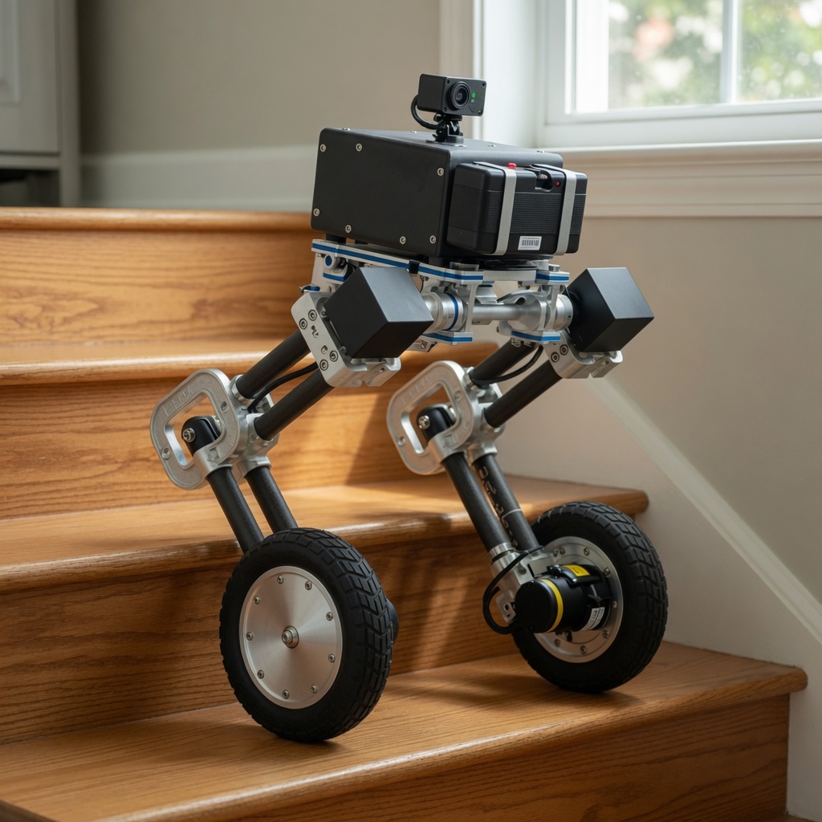
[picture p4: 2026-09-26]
art/concepts/hux-stairs.jpg

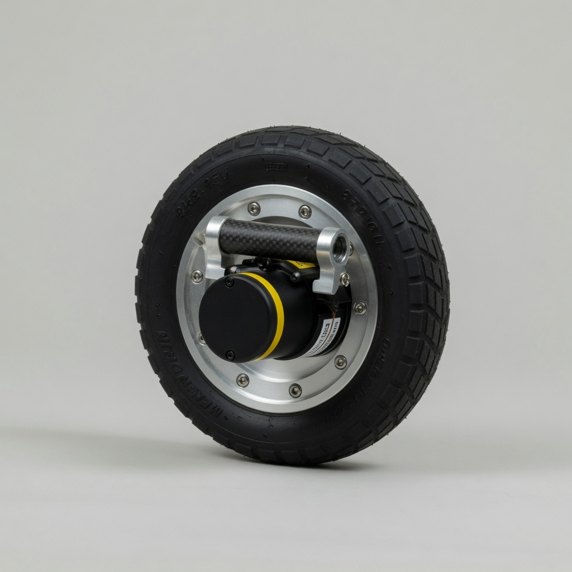
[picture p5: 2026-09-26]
art/concepts/wheel.jpg

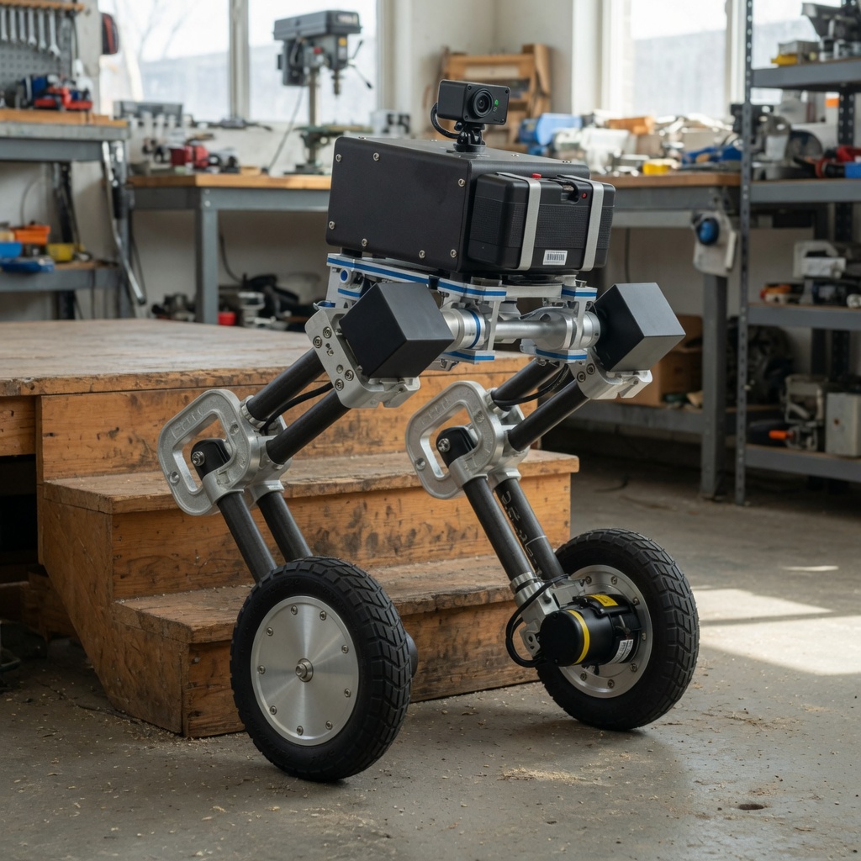
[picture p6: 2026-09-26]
art/concepts/hux-workshop.jpg

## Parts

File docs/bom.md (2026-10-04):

# V1-PROOF budget

**$900 planned ceiling. The ceiling includes shipping, tax and the repair contingency.** The hard limit is strictly under $1,000. The recorded orders below are committed V1-PROOF spend. The previous stair budget is [parked](archive/stair-v1/bom.md).

**Recorded spend: $173.70. Remaining against the planning ceiling: $726.30.** The remaining money includes all unfinished purchases and the reserves. It is not a quote for completion.

## Ordered parts and delivery

| Vendor / ordered part | Ordered quantity | Unit paid | Goods total | Order status |
| --- | ---: | ---: | ---: | --- |
| Pololu 4752 · 30:1 12 V encoder gearmotor | 1 | $60.95 | $60.95 | Received; untested |
| Pololu 4035 · DRV8874 motor driver | 1 | $11.94 | $11.94 | Received; untested |
| Waveshare 22414 · ST3215 servo series (12 V per user) | 2 | $21.19 | $42.38 | Paid; awaiting shipment |
| Amazon Pico 2 with yellow pre-soldered headers | 1 | Not recorded | Not recorded | Received; untested |
| Amazon SparkFun LSM6DSO Qwiic IMU | 1 | Not recorded | Not recorded | Received; untested |

- **Pololu:** The user report recorded 2 October says that the gearmotor and the DRV8874 drivers are received. The exact delivery date, the total driver count, the labels and the inspection remain unrecorded. This paid receipt covers one gearmotor and one driver. The order shipped 28 September via UPS Ground.
- **Waveshare:** Paid. The latest vendor receipt says that the order is not yet shipped. No dispatch or delivery date is confirmed. This receipt does not charge tax separately.
- **Amazon:** The supplied screenshot shows the order placed 2 October with a $30.58 total. The user confirmation recorded 3 October says that both the Pico 2 and the LSM6DSO IMU are received, untested. This confirmation supersedes the screenshot arrival estimate. The item prices, shipping, tax and payment date are not shown.

**Recorded wheel orders cover 1 of 2 motors and 1 of 2 drivers. Not covered by recorded orders: 1 motor and 1 driver.** The first restrained bench channel is ordered. The second wheel channel is still required. Confirm the total received driver count before you buy another driver.

Recorded leg orders cover 2 of 2 ST3215 servos, with 0 still needed. When the servos arrive, make sure that the labels say 12 V. The receipt names the ST3215 series. The user confirmed the voltage variant. [Motor connections and controls](v1-proof-hardware.md).

## Recorded order totals

| Vendor / recorded date | Goods | Shipping / handling | Tax | Order total |
| --- | ---: | ---: | ---: | ---: |
| Pololu / 2026-09-28 (paid) | $72.89 | $10.45 | $5.00 | **$88.34** |
| Waveshare / 2026-09-28 (paid) | $42.38 | $12.40 | $0.00 separately charged | **$54.78** |
| Amazon / 2026-10-02 (ordered) | Not recorded | Not recorded | Not recorded | **$30.58** |
| **Recorded spend** | **Not recorded** | **Not recorded** | **Not recorded** | **$173.70** |

Recorded order totals count each purchase one time. The reference prices below are historical. A payment-service confirmation confirms its vendor order, and we do not count it again. An order-placement date does not establish the payment date. Missing amounts stay unrecorded, never zero. An order total without itemized charges can establish the overall spend while the separate goods and shipping/tax balances remain unknown.

Refer to the [purchase evidence](purchases.md) and the [inventory](parts-on-hand.md) for the delivery and qualification gates.

## Remaining planning allocations

| Allocation | Not yet spent |
| --- | ---: |
| Parts and fixture allowance | Not recorded |
| Shipping, tax and import-charge allowance | Not recorded |
| Repair and overrun reserve retained | $125.00 |
| **Remaining against the planning ceiling** | **$726.30** |

Refer to the inventory for the controller and IMU receipt status. The servo interface, encoder level conversion, current-limit passives, wheels/hubs, protected power and wire harness still need confirmation. Bench-supply ratings remain unconfirmed. Historical carts and unassigned V0-GENESIS parts are not recorded V1-PROOF spend.

## Remaining shopping list

The Pico 2 and the LSM6DSO IMU are received and paid. Two ST3215 servos are also already paid, with arrival unreported. The order ledger above records the other paid parts. Confirm the stock of the support parts before you buy replacements.

| Part / assembly | What remains | Next step |
| --- | --- | --- |
| Pololu 4752 encoder wheel motor | 1 more motor. The complete drive requires two wheel gearmotors of the same model. | Still to buy |
| DRV8874 wheel driver and current-limit passives | Confirm coverage for 2 wheel channels. The receipt covers one driver. The total received count is unconfirmed. Buy a second Pololu 4035 only if one is missing. The current-limit passives still need confirmation. | Check stock first |
| Compatible half-duplex TTL servo interface | 1 interface. The Pico 2 and the IMU are received. The ST3215 bus adapter is a separate part with no confirmed purchase or stock. | Check stock first |
| Rubber wheels, hubs and supported axle hardware | 2 wheel assemblies. Approximately 100 mm wheels. The hubs and the axle support must fit the selected gearmotor and layout. No stock is reserved. | Check stock first |
| Leg reductions, shafts, pivots, bearings, stops and lock pins | Hardware for both legs. Two 3:1 reductions are planned. The printed links are on hand. The transmission and pivot hardware still need inventory confirmation. | Check stock first |
| Manual input / deadman link | 1 usable control link. Confirm a laptop/gamepad or a compatible receiver/transmitter before you buy replacements. | Check stock first |
| Compatible 3S battery | 1 pack. The model, cell count and condition of the current pack are unconfirmed. Reuse a qualified pack or buy one. | Check stock first |
| Compatible balance charger, supply and charge lead | 1 charging setup. Confirm that the current charger and leads match the selected pack before you buy. | Check stock first |
| Regulators and protected power distribution | 9 V servo and 5 V logic rails, plus fuse, kill and return-energy protection. The bench supply is available, with ratings unconfirmed. The robot power/protection parts are not yet confirmed. | Check stock first |
| Wiring, connectors, encoder level shifting and strain relief | Harness for both wheel channels and the servo bus. Confirm the shop stock. The 5 V encoder signals require suitable 3.3 V level conversion. | Check stock first |
| Frame/bracket stock and mechanical fasteners | Remaining structure and assembly hardware. The user reports that the 3D print is complete. Confirm the printed fit and the available fasteners/frame stock before you buy more. | Check stock first |
| Catch frame, rest skids and padding | 1 test fixture / catch setup. Confirm usable shop materials and build the fixture before free-standing trials. | Check stock first |

The original planning caps below cover the full build allocations. The allocations include parts already bought. Missing parts still need quotes or confirmed reuse.

## Original planning caps

We keep these maximum allocations for comparison with the actual spend. They are not a fully quoted remaining cart. Delivery, import charges and unpurchased rows need current quotes. The plan assumes the shop tools on hand and unpaid fabrication labor. New tools or outsourced work must fit this same total, or the design must change. Refer to the [hardware decisions](v1-proof-hardware.md).

**The plan assumes no free inventory.** The confirmed reuse credit is $0. The quantities below are planned build quantities, not ordered quantities. Paid purchases already consume these allocations. Do not add their cost to the $900 ceiling, and do not subtract them again as free reuse.

Give credit for qualified equipment on hand only when it displaces a purchase. Retain the shipping/tax and repair reserves. A Pi, cameras, display and Jetson are outside this build.

| Qty | Item | Unit cap | Total cap | Stage |
| ---: | --- | ---: | ---: | --- |
| 2 | [Pololu 4752 12 V 30:1 encoder gearmotors](https://www.pololu.com/product/4752) | $62.50 | $125.00 | P1 |
| 2 | [Pololu 4035 DRV8874 carriers + current-limit passives](https://www.pololu.com/product/4035) | $20.00 | $40.00 | P1 |
| 2 | [Waveshare ST3215, 12 V variant (9 V qualified rail)](https://www.waveshare.com/product/st3215-servo.htm) | $30.00 | $60.00 | P3 |
| 1 | Two 3:1 reductions, shafts, pivots, bearings, stops and lock pins | $60.00 | $60.00 | P3 |
| 1 | Two rubber wheels, hubs and supported axle hardware | $35.00 | $35.00 | P1 |
| 1 | Pico 2, SparkFun LSM6DSO and half-duplex servo interface | $40.00 | $40.00 | P0 |
| 1 | Manual input/link replacement allowance | $60.00 | $60.00 | P0 |
| 1 | Compatible 3S battery | $35.00 | $35.00 | P1 |
| 1 | Compatible balance charger, supply and lead | $45.00 | $45.00 | P1 |
| 1 | 9 V servo and 5 V logic rails, fuse, kill, regeneration protection | $65.00 | $65.00 | P1 |
| 1 | Wire, connectors, encoder level shifting and strain relief | $30.00 | $30.00 | P1 |
| 1 | Scrap/COTS frame, links, brackets, fasteners and prototype material | $60.00 | $60.00 | P1 |
| 1 | Catch frame, rest skids and padding materials | $20.00 | $20.00 | P1 |
| | **Parts and fixture subtotal** | | **$675.00** | |
| | Shipping, sales tax and any import charges | | $100.00 | Reserved |
| | Repairs, replacement parts and overrun reserve | | $125.00 | Reserved |
| | **Total** | | **$900.00** | |

The difference to $1,000 is $100. If you spend the full difference, you violate the strictly-under-$1,000 requirement. Prefer savings from reuse. Do not change savings into added features.

## Historical reference prices and scope

We checked the price and availability observations that follow on **2026-09-28**. They are not current stock checks or evidence of more purchases. The receipt table above controls the actual spend.

- Pololu 4752 gearmotor: the reference price is $60.95 each. Two of the selected encoder motors fit the $125 allocation. The report above calculates the current purchased quantities and the remaining needs.
- DRV8874 driver (Pololu 4035): the reference price is $11.94 each. Two carriers plus the current-limit passives fit the $40 allowance. The current-limit passives still need confirmation. Measure the 2.5 A limit. The historical stock page permitted backorders. This driver replaces the oversized G2 reference.
- ST3215 servo (Waveshare ST3215 series): the reference price is $16.99–21.99 as a function of the variant. The receipt prices are recorded above. Qualify the hold performance on the regulated 9 V rail. The $60 allocation remains the original cap, with a separate transmission row.
- The original allocation for the Pico 2, the Adafruit LSM6DSOX 4438 and the half-duplex adapter was $40. The IMU reference price on September 28 was $11.95. The October 2 controller/IMU order instead names the SparkFun LSM6DSO IMU. That order has a $30.58 combined total and no itemized charges. The servo interface remains unconfirmed. Keep the original cap and record the remaining costs separately.
- Manual input can reuse RC or a laptop/gamepad with a timed deadman link. The $60 fallback is an allocation, not a claim that a new TBS receiver and transmitter together cost $60.

## Build sequence

P0 makes an inventory of the controls on hand and qualifies them. P1 builds the supported wheel rig and the pinned structure. P2 proves two-wheel balance and slow teleop. P3 adds the two leg servos and their reductions. P4 runs the finish-line trials.

These stages share one budget. Do not add a second two-motor robot to the four-motor cost. A quote that exceeds an allocation consumes the reserve or forces a substitution before purchase.

Sources: the planning caps are in [model.json](../tools/v1-proof/model.json). The paid orders are in [plan-data.json](../tools/living-drawings/plan-data.json), under V1-PROOF `orders`. Refer to the [receipt provenance](purchases.md). Regenerate with `python3 tools/v1-proof/review.py --write`. [Active plan](v1-proof.md) · [Inventory](parts-on-hand.md).

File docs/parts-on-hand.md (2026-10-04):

# V1-PROOF parts and reuse inventory

**2026-10-03 controller/IMU arrival:** the user reports that one **Pico 2 with yellow pre-soldered headers and one LSM6DSO IMU are received**. The inspection, USB and sensor tests are not yet done. The October 2 Amazon order of the user has a **$30.58 combined total**. This brings the recorded project spend to **$173.70** and leaves **$726.30** under the $900 plan. This report supersedes the screenshot arrival estimate.

The item prices, the shipping/tax breakdown and the payment date remain unshown. The LSM6DSO IMU replaces the earlier Adafruit LSM6DSOX selection, subject to sensor qualification. Start the [Pico/IMU bring-up](checklists/2026-10-03-pico-bringup.md). [Remaining shopping list](bom.md#remaining-shopping-list).

**2026-10-02 arrival and 3D-print update:** the user reports that the **30:1 metal gearmotor and the DRV8874 DC motor drivers are received**. The user also reports that the **parts are 3D printed** and ready for the start of the mechanical tests. This changes the Pololu 4752 / 4035 bench baseline to received, untested. The receipt documents one motor and one driver. The total received driver count remains to confirm. The printed revision, material, quantities, dimensions and condition are unrecorded.

The ST3215 servo arrival is not reported. Start the [first mechanical fit session](checklists/2026-10-02-mechanical-fit.md). No fit, load or powered test is recorded yet. The recorded paid spend remains **$143.12**. We infer no more cost and no reuse credit.

**2026-10-01 motor inventory:** the user reports **one servo and two steppers**. The photos identify the servo as **Panasonic MSMD042G1A**. One photographed stepper has the label Astrosyn 610-024. The second label is unverified. These are untested bench/future reuse candidates, with no V1-PROOF substitution or reuse credit. [Photo evidence, specifications and fit assessment](#motor-stock-recorded-2026-10-01).

**2026-09-29 receipt reconciliation:** **one Pololu 4752 gearmotor and one DRV8874 driver are shipped**. **Two ST3215 servos are paid, and the latest vendor record says that they wait for shipment.** The recorded V1-PROOF spend is **$143.12**. This total includes shipping/tax.

The user confirmed the servo 12 V variant. Examine the labels on arrival. A bench supply is available, with ratings unconfirmed. [Paid orders and delivery evidence](purchases.md) · [Single-leg bench preparation](one-leg-bench.md).

**RobStride belongs to the future full-size Hux**, not to the current V1-PROOF build. The clarification of the user resolves the earlier ambiguity from the vendor-CAD notes. It does not confirm a RobStride order. The receipt establishes one purchased DRV8874 driver. The planned two-wheel robot still needs a second Pololu 4752 gearmotor. Confirm the received driver count and any more purchases before you decide if another driver is necessary.

Purchased parts count as new cash spend. We infer no reuse credit.

| Part / candidate reuse | Availability / condition | V1-PROOF use | Reuse credit currently counted |
| --- | --- | --- | ---: |
| F765-Wing, F722 boards, Mamba board | Historical mentions; verify exact board | MCU + built-in IMU if pins/timing work | $0 |
| ESP32 | Historical mention; revision/IMU unknown | Alternative controller or manual-link bridge | $0 |
| TBS Nano RX and compatible transmitter | Receiver mentioned historically; full link unconfirmed | Manual input | $0 |
| Pi 5 / existing laptop | Historical Pi mention; availability unconfirmed | Off-robot logging; no onboard Pi required | $0 |
| Pico 2 with yellow pre-soldered headers | 1 received per user and screenshot 2026-10-03; untested; individual price unshown within $30.58 controller/IMU order | USB/LED bring-up, then C/C++ controller qualification | $0 |
| SparkFun LSM6DSO Qwiic IMU | 1 received per user 2026-10-03; untested; individual price unshown within the $30.58 controller/IMU order | Main SPI and data-ready sensing; replaces the earlier LSM6DSOX choice after qualification | $0 |
| Pololu 4752 encoder gearmotors | 1 received per user 2026-10-02, untested; $60.95 goods, part of the $88.34 paid Pololu order; second motor still required | Dry-fit the received motor, then qualify one restrained wheel channel | $0 |
| ST3215 12 V servos | 2 paid; $42.38 goods + $12.40 shipping = $54.78; awaiting shipment in latest receipt; 12 V variant confirmed by user | Supported single-leg bench now; robot height adjustment after pinned-leg balance | $0 |
| Pololu 4035 DRV8874 drivers | Received per user 2026-10-02, untested; total delivered count pending; receipt covers 1 at $11.94 goods | H-bridge and current limiting for each wheel motor; confirm coverage of both channels | $0 |
| 3D-printed mechanical parts | Printed per user 2026-10-02; revision, material, quantities and fit unrecorded | Passive geometry and packaging checks; powered mounts and load capacity remain unqualified | $0 |
| Servo interface / adapter | Purchase/availability unconfirmed | Half-duplex TTL commands and feedback | $0 |
| Bench supply | Available per user 2026-09-29; model, voltage/current range and reverse-energy behavior pending | Sequential single-actuator tests after rating/interface checks | $0 |
| Panasonic MSMD042G1A industrial servo | 1 on hand per the user 2026-10-01; two photo views; untested, drive/harness/supply unknown | Bench/future mechanism candidate; 200 V-class drive and mass conflict with current proof | $0 |
| Stepper motors; one labeled Astrosyn 610-024 | 2 on hand per the user 2026-10-01; only one label verified; ratings and condition unknown | Positioning/fixture candidates after identification; no current axis assigned | $0 |
| Battery and balance charger | Cell count, condition and models unknown | Compatible 3S-class system or deliberate requalification | $0 |
| Wheels, hubs, bearings, belts, fasteners | None reserved | Approximately 100 mm wheel package and simple legs | $0 |
| Aluminum, plywood, tube, wire, connectors | Shop stock not inventoried | Frame, fixture and harness | $0 |

For each confirmed item, record the date, exact variant, quantity, condition, electrical limits and measured mass/envelope. Also record if the item is available for Hux. A vendor CAD file is not owned hardware. The presence of a board does not establish spare pins or compatible logic levels. A receiver needs a usable transmitter/link.

The [budget](bom.md) separates the **$173.70 recorded spend** from the **$900 planning ceiling**. Refer to the [order ledger](purchases.md) for the two itemized paid orders and the controller/IMU order with an unshown charge breakdown. New ordered components count one time as project spend. They are not zero-cost reuse. The remaining $726.30 includes unpurchased parts and reserves. The unknown breakdown of the new order prevents exact remaining allocations for parts and for freight/tax.

Give credit for equipment on hand only when it displaces a purchase. Do not count the same item two times, and do not spend the savings on new features. Keep the reserve. [Shop capabilities](capabilities.md) describes tools, not component stock.

The control baseline is [Pico 2 + SPI SparkFun LSM6DSO, Pololu 4035 wheel drivers and a compatible ST3215 interface](v1-proof-hardware.md). The Pico 2 and IMU receipt are confirmed. The servo interface and all electrical qualification remain open. The historical reuse candidates above get credit only after qualification.

## Motor stock recorded 2026-10-01

**Availability:** the user reports **one specialty servo and two stepper motors** on hand as reuse candidates. These are three physical motors, not three models. The two Panasonic photographs show opposite sides of the same servo. One stepper label is photographed. The identity of the second stepper is unverified.

No functional test results are recorded for Hux. The purchase prices, service history and storage location are unknown. **The V1-PROOF reuse credit remains $0.**

### Photo evidence

We retrieved the original JPEG bytes from Library and visually inspected them on 2026-10-01. The copies below keep their original filenames. We record the Library identity explicitly, so that you can trace a photo outside Library.

| Original photo | Library ID | What the pixels establish |
| --- | --- | --- |
| [IMG_9982.jpeg](assets/motor-inventory/2026-10-01/IMG_9982.jpeg) | `libfile_1ce799a09ee881918d8e30e7bddfccfa` | Panasonic model and main electrical/speed nameplate |
| [IMG_9981.jpeg](assets/motor-inventory/2026-10-01/IMG_9981.jpeg) | `libfile_c8ba5fc86b088191903ae1f0f1a11db9` | Opposite side of the servo; continuous torque, duty and enclosure label |
| [IMG_9983.jpeg](assets/motor-inventory/2026-10-01/IMG_9983.jpeg) | `libfile_c11fb44b4dbc8191b21fdada1d236742` | One Astrosyn motor marked 610-024, with wire leads |

### Panasonic MSMD042G1A — quantity 1

**Directly legible on the photos:** Panasonic AC servo motor, model **MSMD042G1A**. The input is **3-phase AC 106 V, 2.6 A**. The rated output is **0.4 kW**, the rated frequency is **200 Hz** and the rated speed is **3000 r/min**. The continuous torque is **1.3 N·m**, the duty is **S1** and the enclosure is **IP65**.

Cable sections are visible, but their ends, completeness, pinout and condition are not established. Exterior marks and shaft residue are visible. These do not establish the mechanical or electrical health. The availability of a drive for this motor, a complete power/encoder harness, a supply and a gearbox is unknown.

**Manufacturer specifications, checked for this exact suffix on 2026-10-01:** Panasonic identifies this motor as a discontinued MINAS A5, low-inertia motor. It has a nominal mass of **1.2 kg**, a **60 mm square flange**, a round shaft, no oil seal and **no holding brake**. The encoder is **20-bit incremental** (1,048,576 positions/revolution). The rated torque/speed are 1.3 N·m / 3000 rpm. The momentary peak torque is **3.8 N·m**, and the maximum speed is **5000 rpm**.

These maxima are separate limits, not a continuous operation point. The IP65 rating does not include the shaft portion that turns and the lead-wire ends. The actual mass, shaft dimensions, mount fit and condition remain unmeasured. [Panasonic MSMD042G1A specification and applicable-drive table](https://industry.panasonic.com/global/en/products/motor/fa-motor/ac-servo/number/msmd042g1a).

**Drive and voltage constraint:** the 106 V motor rating on the nameplate is not a supply-selection instruction. Panasonic lists 200 V-class compatible drives. One listed example, **MBDHT2510**, takes **200–240 VAC** main/control input and uses analog/pulse commands. It supports the 20-bit **5-wire serial** feedback of the motor. That drive is nominally **1.0 kg** and has no built-in regenerative resistor.

It is an example to identify equipment on hand, not a purchase recommendation. Other listed drive variants have different command interfaces, and RTEX is one of them. The motor model alone does not establish the installed control protocol. The USB on this example drive is for parameter settings and status readout. [Panasonic MBDHT2510 specifications](https://industry.panasonic.com/global/en/products/motor/fa-motor/ac-servo_driver/number/mbdht2510).

**Hux assessment — engineering inference:** keep this motor as bench/future-project stock. A geared position axis, a transmission experiment or a restrained actuator test fixture is possible after drive qualification. It is a poor fit for the active V1-PROOF. The bare motor is 40% of the 3.0 kg maximum of the robot, before the drive, supply and transmission. Its drive requirements do not match the 3S / 9 V architecture or the ST3215 TTL interface. One motor cannot supply a matched two-wheel pair.

Continuous 1.3 N·m is useful, but a 3000 rpm motor needs an application-specific reduction for slow joints/wheels. Examine the torque against speed, duty, transmission efficiency/backlash, reflected inertia, shaft loads and total mass. Peak torque is not sustained joint torque. The motor has no holding brake. Thus a gravity-loaded mechanism needs a qualified restraint or hold device when the power is removed. This motor does not establish a full-size Hux actuator choice, and it does not displace the future RobStride work.

### Stepper stock — quantity 2 total

**Direct photo evidence:** one motor has the marks **ASTROSYN**, **610-024** and `www.astrosyn.com`. Wire leads and surface wear are visible. No current, voltage, step angle or torque rating is legible. This view does not establish the complete lead count, the winding connections or the lead condition. The statement of the user establishes two steppers on hand. **Do not give both the label 610-024 until you examine the other unit.**

**Manufacturer verification:** we found no exact 610-024 datasheet in the [Astrosyn technical-data index](https://www.astrosyn.com/technical-data-sheets) or in exact-model searches on 2026-10-01. Thus the model-specific phase current, voltage, resistance/inductance, winding scheme, step angle, torque-speed curve, frame size, mass and shaft dimensions remain **unknown**. “024” is not evidence of a 24 V rating. A custom/OEM status is possible but unconfirmed. We do not substitute the specifications of a similar model.

**Hux assessment — engineering inference:** the steppers can be useful for a slow position fixture, a small linear stage or a mechanism prototype. First we must identify and measure them. No axis is assigned. Neither stepper is qualified to replace the encoder wheel motors or the feedback leg servos of V1-PROOF. The usable torque in motion, thermal duty, position feedback and response to lost steps are not established.

Make sure of the complete winding arrangement and the rated phase current before you select a compatible current-regulated stepper driver. Its supply voltage and current value must agree with the documented motor/driver configuration.

Winding voltage and driver bus voltage are different constraints. The driver, cables/connectors, power supply, encoder, gearbox and tested condition are all unknown. Measure the mass and the mount/shaft geometry. Compare the torque in motion at the necessary speed and reduction, not only the holding torque. The Astrosyn [drive-selection guide](https://www.astrosyn.com/wp-content/uploads/2015/10/Guide-to-Stepper-Motor-Drive-Selection.pdf) and [motor-selection guide](https://www.astrosyn.com/wp-content/uploads/2015/10/Guide-to-Stepper-Motor-Selection.pdf) give general selection principles, not ratings for 610-024.

### Evidence needed before reuse

1. Record the label of the second stepper and all other rating/wire labels on both steppers, or their original machine documentation. If no other label exists, get the exact-model winding/current specifications from Astrosyn.
2. Make an inventory of each Panasonic drive by its full model label, plus both cable ends/connectors and each external brake/gearbox. Make sure of the exact motor/encoder/drive combination and the command interface in its manual.
3. Record the measured mass, envelope, shaft/mount dimensions and unpowered condition for each unit. Before you plan a restrained powered test, resolve the intended load, reduction, supply, current/thermal limits, fault response and return-energy behavior.

**Disposition:** inventory only. Do not energize unknown wires, and do not buy a driver or a supply until those details are verified. The [locked V1-PROOF hardware](v1-proof-hardware.md), the [mass/power scope](v1-proof.md) and the current purchase totals remain the basis for the current robot.

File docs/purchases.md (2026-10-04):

# V1-PROOF recorded orders and delivery status

**Updated 2026-10-03: $173.70 recorded spend.** The user confirms that the **Pico 2 and LSM6DSO IMU are both received**, untested. The October 2 Amazon order of the user totals **$30.58** in the supplied screenshot. We count this total one time, together with the earlier $143.12 in Pololu and Waveshare receipts. This receipt confirmation supersedes the screenshot arrival estimate.

The Amazon order does not show the item prices, shipping, tax and payment date. **$726.30 remains** under the $900 plan. [Pico/IMU bring-up](checklists/2026-10-03-pico-bringup.md) · [Remaining shopping list](bom.md#remaining-shopping-list).

**2026-10-02 mechanical arrival:** the user reports that the 30:1 metal gearmotor and the DRV8874 drivers are received. The paid order covers one motor and one driver. The total delivered driver count remains to confirm. The user also reports that the parts are 3D printed. Fit, firmware and physical performance remain WIP. [First mechanical fit session](checklists/2026-10-02-mechanical-fit.md).

## Ordered parts and delivery

| Vendor / part | Ordered quantity | Unit paid | Goods total | Latest evidence |
| --- | ---: | ---: | ---: | --- |
| Pololu **4752**, 30:1 Metal Gearmotor 37Dx68L mm, 12 V, 64 CPR encoder, helical pinion | **1** | $60.95 | $60.95 | Received per user report recorded 2026-10-02; untested |
| Pololu **4035**, DRV8874 Single Brushed DC Motor Driver Carrier | **1** | $11.94 | $11.94 | Drivers received per user 2026-10-02; total received count pending; untested |
| Waveshare **22414**, ST3215 servo series; **12 V variant confirmed by user** | **2** | $21.19 | $42.38 | Paid 2026-09-28; vendor receipt says **Awaiting Shipment** |
| Pico 2 with yellow pre-soldered headers, via Amazon | **1** | Not recorded | Not recorded | Received per user and screenshot 2026-10-03; untested |
| SparkFun **LSM6DSO Qwiic** IMU, via Amazon | **1** | Not recorded | Not recorded | Received per user confirmation 2026-10-03; untested |

The September 28 Pololu shipment notification estimated delivery on **Thursday, October 1, 2026**. The report of the user, recorded October 2, now establishes receipt. The exact delivery date and a carrier tracking check are not recorded. The available records do not establish a servo dispatch date or arrival date. Inspect the servo labels. The receipt names the ST3215 series, but the 12 V choice comes from the September 29 confirmation of the user.

## Recorded spend

| Paid order | Goods | Shipping / handling | Tax | Total paid |
| --- | ---: | ---: | ---: | ---: |
| Pololu, 2026-09-28 | $72.89 | $10.45 | $5.00 | **$88.34** |
| Waveshare, 2026-09-28 | $42.38 | $12.40 | $0.00 separately charged | **$54.78** |
| Amazon, ordered 2026-10-02; payment date unshown | Not recorded | Not recorded | Not recorded | **$30.58** order total |
| **Recorded V1-PROOF spend** | **Not recorded** | **Not recorded** | **Not recorded** | **$173.70** |

The Pololu invoice explicitly records $88.34 paid and $0 due. The Waveshare payment confirmation and the PayPal receipt for that order both record $54.78. Do not add the payment-service confirmation as a second purchase.

The two earlier orders have a known breakdown of $115.27 goods, $22.85 shipping and $5.00 tax. The new screenshot supplies only a combined order total. Do not infer individual prices, and do not treat missing charges as zero. Record its $30.58 one time in the order ledger. Leave the purchase-card goods costs unknown.

Against the **$900 planning ceiling**, **$726.30 remains**. This amount includes everything still to buy and the retained reserves. With the **$125 repair reserve intact**, $601.30 remains for parts and shipping/tax combined. Their exact separate balances are unknown until the Amazon breakdown is available. These are remaining allocations, not a quote to complete the robot.

The hard all-in limit remains strictly below $1,000. [Full budget](bom.md).

## What this locks into the design

- **The first wheel channel:** the received Pololu 4752 gearmotor connects through a harness to a received DRV8874 driver. Connect them after the identification and electrical checks. The encoder of the gearmotor feeds the Pico 2 through level conversion. [Connection plan](v1-proof-hardware.md).
- **The two leg actuators:** the two ST3215 servos define the planned reduced leg drive. This choice is subject to the arrival-label check and the 9 V mounted-load qualification.
- **The full robot:** still two wheel motors, two drivers and two leg servos. **Paid receipts cover one wheel motor and one driver.** The second wheel motor is still required. Confirm the delivered driver count and any more orders before you buy another driver. The one-channel bench is part of the same robot budget.
- **Controller and IMU:** one Pico 2 and one LSM6DSO IMU are received, untested. The received LSM6DSO IMU replaces the earlier Adafruit LSM6DSOX selection. This replacement is subject to arrival identification and qualification. Start with the USB/LED checks, then do the raw sensor readback and the timing check. [Connection baseline](v1-proof-hardware.md).
- **Support parts:** the servo bus interface, encoder level conversion, current-limit passives, wheels/hubs, protected power and wire harness still need inventory/receipt confirmation. A bench supply is available, but it is not yet rated or qualified.

An ordered part is a design commitment, not proof of delivered quantity, mechanical fit or tested capability. If bench evidence rejects a component choice, reopen that choice explicitly. Do not silently substitute another actuator family. [Inventory](parts-on-hand.md) · [Control architecture](software.md) · [Single-leg bench](one-leg-bench.md).

## Evidence and maintenance

This record is a read-only reconciliation of these sources: the September 28 Pololu order and shipment e-mails, the UPS shipment notification, the Waveshare payment confirmation and the PayPal receipt for the Waveshare order. We reviewed them on September 29, 2026. The September 29 clarification of the user supplies the ST3215 voltage variant.

Private receipts remain in the mailbox. We intentionally omit order identifiers, addresses, payment details and tracking links from this public repository.

The October 2 report of the user establishes the motor/driver receipt and the completed 3D printing. It supplies no new quantity breakdown, payment, inspection result or test measurement. We keep the receipt quantities and amounts. Any more driver costs and the print costs remain unrecorded.

The October 3 report of the user and the supplied Amazon order screenshot establish two facts. They establish the Pico 2 receipt and the $30.58 October 2 controller/IMU order. The screenshot lists the Pico 2 and the SparkFun LSM6DSO. The manufacturer specifications identify the named breakout as SEN-18020. The received label is still to verify.

The user then confirms, on the October 3 record, that both the Pico 2 and the IMU are received. This confirmation supersedes the relative delivery estimate.

The exact carrier delivery time remains unrecorded. No new board test or sensor test is reported. We omit the private account details, the order identifier and the unredacted screenshot from this public repository.

The published order records are in [plan-data.json](../tools/living-drawings/plan-data.json), under V1-PROOF `orders`. The purchase-card `actualCost` is the goods-only line total. The `orders[].paidTotal` includes the recorded shipping/tax of that order. The budget generator and the homepage both use those order records. Update this evidence summary and the inventory in the same change as the order records. Keep unknown amounts as `null`.

Never change a reference price or an unconfirmed legacy purchase into paid V1-PROOF spend.

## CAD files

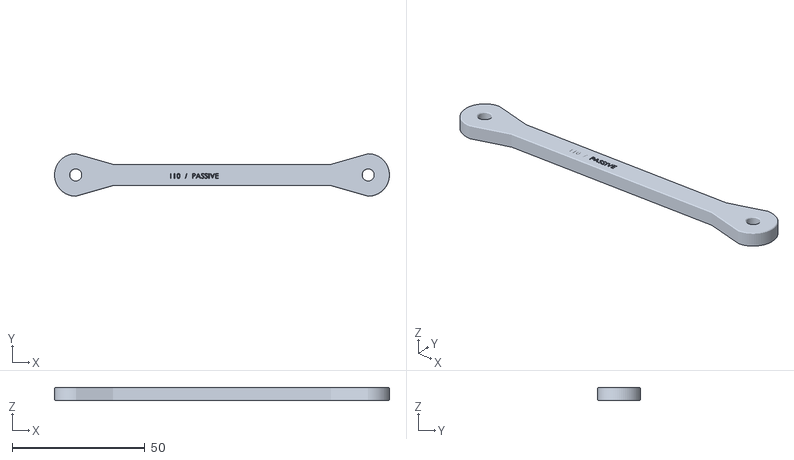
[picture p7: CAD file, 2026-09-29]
cad/prints/v1-proof-r01/stl/03_link_110.stl
126.0 x 16.0 x 5.00

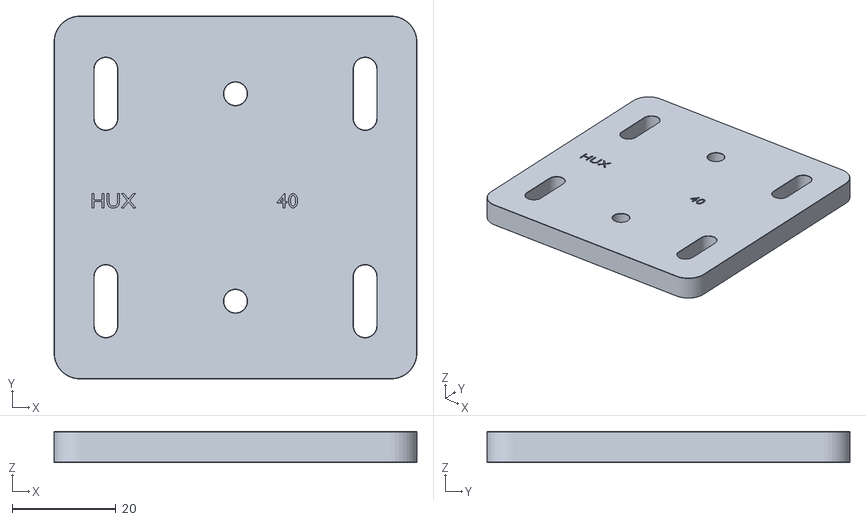
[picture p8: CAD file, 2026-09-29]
cad/prints/v1-proof-r01/stl/02_fixed_pivot_plate.stl
70.0 x 70.0 x 6.00

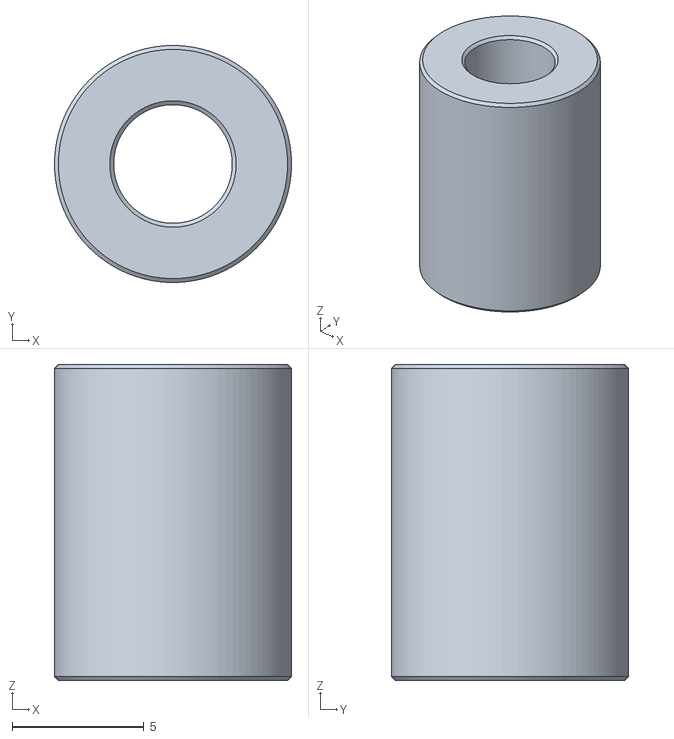
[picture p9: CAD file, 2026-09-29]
cad/prints/v1-proof-r01/stl/06_spacer_12mm.stl
9.00 x 9.00 x 12.0

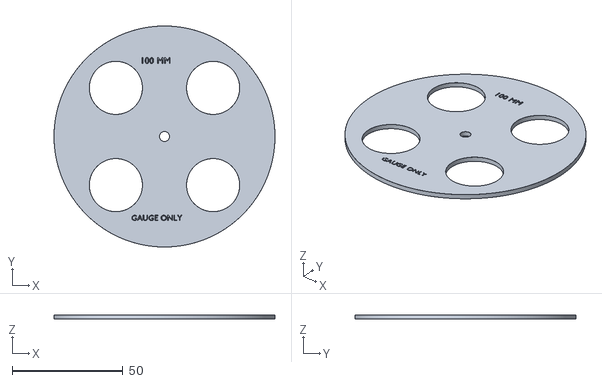
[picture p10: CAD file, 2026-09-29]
cad/prints/v1-proof-r01/stl/08_wheel_envelope_100.stl
100.0 x 100.0 x 2.00

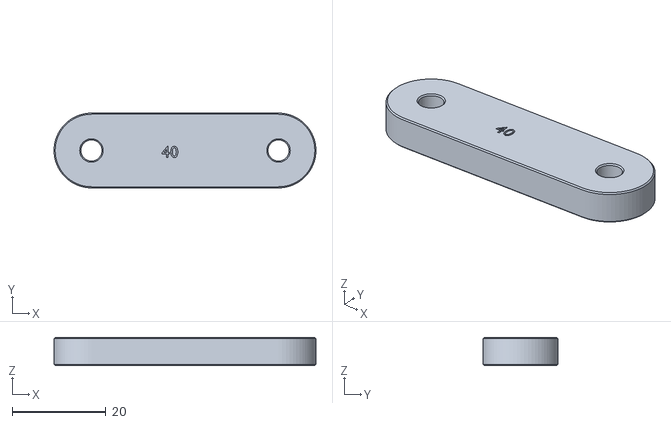
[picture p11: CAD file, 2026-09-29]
cad/prints/v1-proof-r01/stl/04_carrier_40.stl
56.0 x 16.0 x 6.00

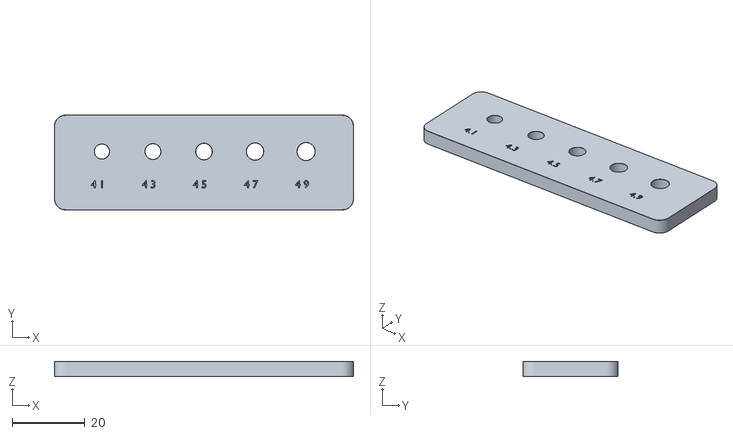
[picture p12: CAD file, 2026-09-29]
cad/prints/v1-proof-r01/stl/07_hole_fit_coupon.stl
82.0 x 26.0 x 4.00

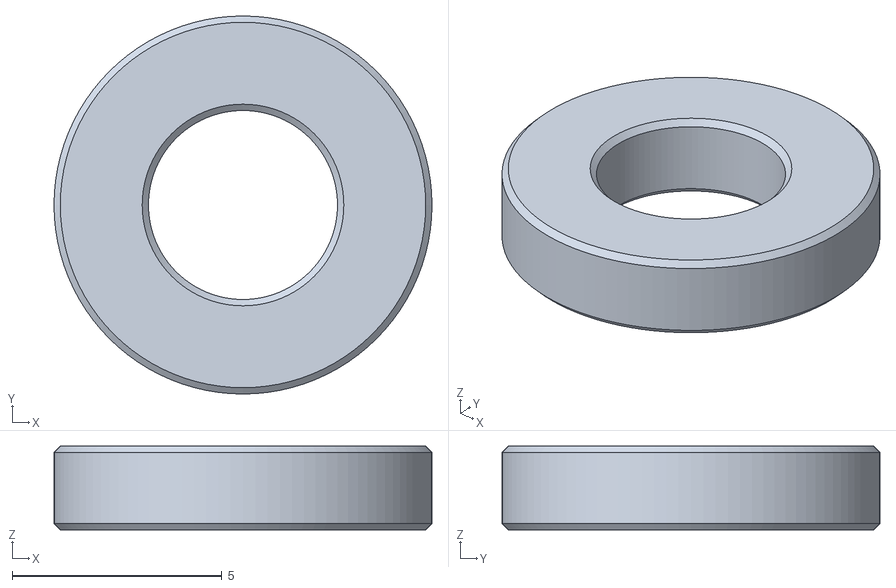
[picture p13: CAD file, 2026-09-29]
cad/prints/v1-proof-r01/stl/05_spacer_2mm.stl
9.00 x 9.00 x 2.00

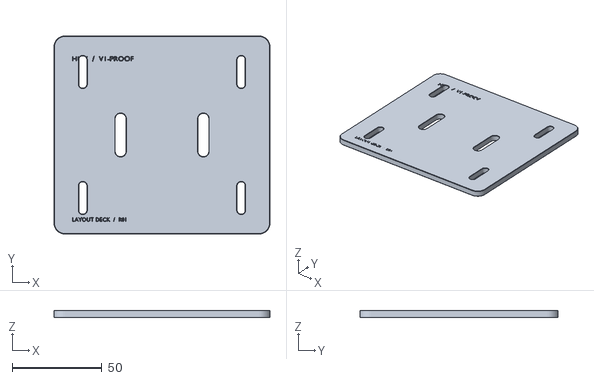
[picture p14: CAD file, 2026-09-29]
cad/prints/v1-proof-r01/stl/01_layout_deck.stl
120.0 x 110.0 x 4.00

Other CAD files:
cad/prints/v1-proof-r01/hux-v1-proof-r01.blend

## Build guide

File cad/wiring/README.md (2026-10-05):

# V1-PROOF electrical atlas

Rev B, dated 2026-10-04. [Verification record and sources](../../docs/wiring-atlas.md) / [site integration](../../tools/living-drawings/electrical.html).

Five coordinated SVG sheets are the editable, resolution-independent deliverables. The matching PNGs provide raster previews, up to 4800 pixels wide. All PDF pages use 11 x 17 inch paper in landscape orientation, with 0.5 inch margins. The [five-page PDF](v1-proof-wiring-atlas.pdf) keeps vector text and paths.

The [system PDF](v1-proof-el-01-overview-11x17.pdf) and the [motor PDF](v1-proof-el-05-both-wheels-11x17.pdf) each contain one sheet. The Electrical page includes a PDF view and a download link beside each diagram. Select 11 x 17 inch paper, landscape orientation and 100% scale. The PDFs already include the margins. Disable printer headers and footers.

The print layout date is October 5, 2026. EL-01 uses less vertical space, with full-size text and circular symbols. EL-01 and EL-05 use white backgrounds without the dot grid. The source audit remains Rev B, dated October 4, 2026.

| Sheet | Drawing |
| --- | --- |
| EL-01 | [Complete system wiring](v1-proof-el-01-overview.svg) — every proposed external conductor and both motor channels |
| EL-02 | [Pico 2 and SPI IMU](v1-proof-el-02-pico-imu.svg) — physical pins and the seven-wire sensor harness |
| EL-03 | [Wheel motor and encoder harness](v1-proof-el-03-wheel-harness.svg) — carrier pads and motor cable details |
| EL-04 | [Power distribution and servo bus](v1-proof-el-04-power-servo.svg) — isolation, actuator cut and unresolved interfaces |
| EL-05 | [Both wheel motors — every wire](v1-proof-el-05-both-wheels.svg) — separate left and right paths |

The [searchable wire register](v1-proof-wire-register.html) maps EL-01 conductor IDs to named endpoints. EL-05 uses terminal names, which you can search in the same register. The [JSON register](v1-proof-netlist.json) is the machine-readable review aid. IDs identify proposed external connections. They do not release a connector pinout, wire gauge or internal circuit.

Drawing logic lives in [build.py](build.py) and [complete.py](complete.py). The same SVG supplies the website diagram and its PDF. Do not edit the PDFs or PNGs by hand. Keep electrical source changes and regenerated exports in the same commit.

Run these commands from the repository root. The Python command rebuilds all five SVGs and both registers:

```sh
python3 cad/wiring/build.py
```

For PNG/PDF export, `render.mjs` uses Sharp and Playwright. Set `NODE_PATH` to the installed packages. When the bundled browser of Playwright is not available, you can set `CHROME_PATH` to a local Chromium-compatible executable. The Codex bundled workspace runtime provides the packages. The export needs no network call.

```sh
node cad/wiring/render.mjs
```

The export command also rebuilds the SVGs and registers before it creates the PDFs and PNGs. It records source and output hashes in `v1-proof-export-manifest.json` only after all exports succeed. `--png-only` does not update this record.

After each electrical change, run the export command, inspect both single-sheet PDFs and run these checks:

```sh
python3 cad/wiring/exports.py
cd tools/living-drawings
npm run build
npm run test:site
```

The site build checks the export record before it changes the output directory. A changed source, SVG, PDF or PNG stops the build until you regenerate the exports. This check also applies to the production publisher. Publish the complete `dist/site` directory through the normal deployment process.

The figures describe source-checked pinouts and proposed interfaces. Dashed blocks remain unselected circuits. None of these outputs closes a physical harness, electrical protection or powered-motion gate.

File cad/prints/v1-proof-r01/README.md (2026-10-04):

# V1-PROOF R01 — passive PLA mockup

**Design printer: Bambu X1C. Design material: PLA for this first phase. Status: the user reported the prints on 2026-10-02, and the printed revision, the material and the fit measurements remain to record.**

The user also reports the 30:1 motor and the DRV8874 drivers received. Confirm that the prints match R01. Then use the [first mechanical fit session](../../../docs/checklists/2026-10-02-mechanical-fit.md). No fit, load or powered-test result is recorded.

This full-scale kit checks the proposed body footprint, the parallel-link motion and the lateral spacing by hand. It is **not a powered assembly, a load-qualified robot leg or a released actuator mount**. Bearings, drivetrain interfaces and motor/servo mount patterns wait for measured hardware.

The Blender project contains separate printable, flat components and a passive assembly scene. The individual STLs are the slicer inputs. The manifest and the geometry audit describe the generated revision. The ZIP collects the kit. The assembly placement does not establish a structural connection between the layout deck and the pivot plate.

- [Download the complete print kit](hux-v1-proof-r01-print-kit.zip)
- [Open the Blender project](hux-v1-proof-r01.blend)
- [Print the fit coupon first](stl/07_hole_fit_coupon.stl)
- [Assembly dimensions and spacer layout](assembly-guide.svg)
- [Independent STL validation report](stl-validation.json)

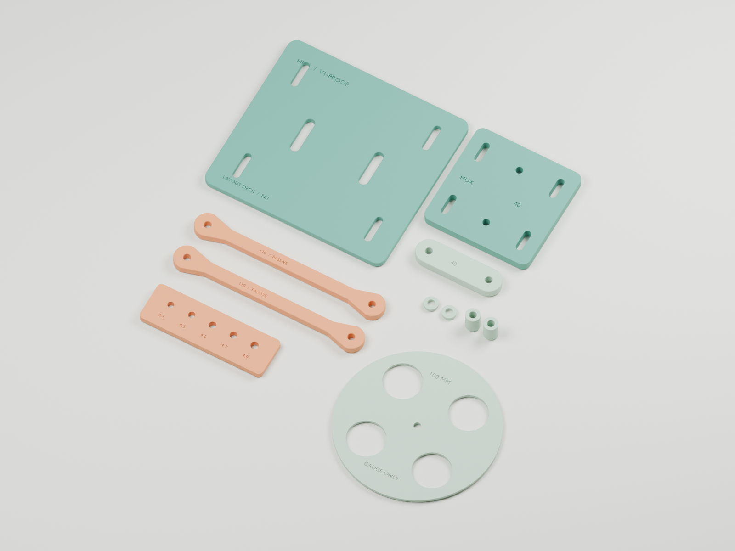
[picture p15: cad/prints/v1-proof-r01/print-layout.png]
Flat printable components


## Print the fit coupon first

Import at **100% scale, in millimeters**. Start with `07_hole_fit_coupon.stl`. Its nominal holes are 4.1, 4.3, 4.5, 4.7 and 4.9 mm. Measure the printed coupon and try the actual intended M4 hardware before you print the linkage.

The other parts provisionally use **4.5 mm holes**. That is a design allowance, not a measured fit. If the coupon shows a poor fit, revise the holes or the slicer compensation deliberately. Do not scale the whole kit to change the hole clearance.

A first PLA draft profile is **0.20 mm layers, four walls and 40% infill**, printed flat without supports. Use **100% infill for the small spacers**. These settings are provisional and do not establish strength or fit. Inspect the slicer preview and the first print before you commit the remaining parts.

## Components

Dimensions are millimeters. Quantities are for **one passive leg**.

| Part | Qty | Nominal geometry / purpose |
| --- | ---: | --- |
| 01 `layout_deck` | 1 | 120 × 110 × 4; proof body footprint with generic M4 slots and cable slots; packaging reference |
| 02 `fixed_pivot_plate` | 1 | 70 × 70 × 6; two pivots 40 apart |
| 03 `link_110` | 2 | 126 × 16 × 5 overall; **110 hole-center spacing**, 8-wide neck |
| 04 `carrier_40` | 1 | 56 × 16 × 6; two pivots 40 apart |
| 05 `spacer_2mm` | 2 | 9 outside diameter, 4.5 bore, 2 high |
| 06 `spacer_12mm` | 2 | 9 outside diameter, 4.5 bore, 12 high |
| 07 `hole_fit_coupon` | 1 | 82 × 26 × 4; five trial hole diameters listed above |
| 08 `wheel_envelope_100` | Optional 1 | 100 diameter × 2; clearance reference only, **not a usable wheel** |

## Assemble and check by hand

1. Clean the prints. Measure the holes, both 110 mm link center distances and both 40 mm pivot separations. Select the fasteners against the actual printed stack. Bolt lengths, washer thicknesses and nut clearances are **not confirmed for your stock**.
2. Keep the fixed plate and the carrier behind both links. Measure the lateral depth outward from the back of each plate. The plate occupies **0–6 mm**. In the Blender assembly, outward depth is along negative world Y. World Z is vertical.
3. Put a **2 mm spacer at each end of the lower link**. The lower-link depth is then **8–13 mm**. Put a **12 mm spacer at each end of the upper link**. The upper-link depth is then **18–23 mm**. Both links connect the same fixed plate to the same carrier. This is a parallelogram, not a thigh and a shin in series.
4. Install only hardware that clears the other link through the full travel. The geometry screen assumes a **9 mm diameter hardware envelope at every pivot** and an **8 mm link neck**. At 15°, the projected clearance is approximately `40 sin(15°) − (9 + 8)/2 = 1.85 mm`. This is a nominal geometric allowance. Actual heads, nuts, washers, print error and lateral play can use all of it. Bolts and hardware on the near link must end below the far link. Check the actual stack. Do not assume that an M4 head fits the envelope.
5. Support the assembly. Sweep it gently by hand from **15° to 45° rearward from downward vertical**, through the **30° neutral** pose. Check the intermediate positions, both approach directions, the pivot hardware and the carrier clearance. Record binding, play and interference. Do not force the mechanism. The optional wheel disc helps you inspect the 100 mm side-view envelope. It does not establish motor, hub, tire or lateral clearance.

This revision has no powered-motion or applied-load qualification. Use the observations to revise the next fixture. Record the actual dimensions before you add purchased actuators.

## Geometry sources

- [Single-leg bench plan](../../../docs/one-leg-bench.md): 110 mm links, 40 mm pivot spacing, 15–45° range and clearance concerns.
- [Full-scale paper template](../../layouts/one-leg-bench-template.svg) and [V1-PROOF envelope](../../layouts/v1-proof.svg).
- [Numerical model](../../../tools/v1-proof/model.json) and [session record](../../../docs/checklists/one-leg-bench-session.md).

These prints are a new mockup interpretation of those sources. Their printable sections and provisional M4 interfaces are not previously validated hardware.

## Regenerate or revise

Edit `build.py`, then run it with Blender in a separate background process:

```sh
/Applications/Blender.app/Contents/MacOS/Blender --background --python-exit-code 1 --python cad/prints/v1-proof-r01/build.py
python3 cad/prints/v1-proof-r01/validate_stl.py
```

The generator overwrites the Blender project, the STLs, the renders, the manifest and the geometry audit in this revision folder. The validator independently reads the exported STL triangles. It checks closed solids, triangle winding, volume, millimeter bounds, bed fit, bores and pivot spacing. Rebuild the ZIP after revisions. The render colors identify the components. Single-color PLA is sufficient.

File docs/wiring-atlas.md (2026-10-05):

# V1-PROOF wiring atlas — Rev B

**Revision dated October 4, 2026. This is a source-checked build-plan drawing. The physical harness and circuit release remain open.** The [Electrical page](../tools/living-drawings/electrical.html) leads with the full system schematic and a separate two-motor sheet. Enlarge a sheet, choose Read labels, and pan to inspect individual conductors. Download the [five-page printable atlas](../cad/wiring/v1-proof-wiring-atlas.pdf) or search the [wire register](../cad/wiring/v1-proof-wire-register.html) by conductor ID, signal or endpoint.

| Sheet | Drawing | Coverage |
| --- | --- | --- |
| EL-01 | [Complete system wiring](../cad/wiring/v1-proof-el-01-overview.svg) | Individual proposed external conductors, both wheel motors and drivers, controller, sensor, power branches, hardware enable and servo bus |
| EL-02 | [Pico 2 + IMU](../cad/wiring/v1-proof-el-02-pico-imu.svg) | Component-side pin maps and seven-wire main SPI connection |
| EL-03 | [Wheel harness](../cad/wiring/v1-proof-el-03-wheel-harness.svg) | Exact DRV8874 pad order, motor lead colors, encoder conversion and wheel GPIOs |
| EL-04 | [Power + servo bus](../cad/wiring/v1-proof-el-04-power-servo.svg) | Power-cut boundary, VSYS isolation, TTL interface and unresolved protection circuits |
| EL-05 | [Both wheel motors — every wire](../cad/wiring/v1-proof-el-05-both-wheels.svg) | Separate left and right motor leads, encoder supply and feedback, driver command and monitoring, and gated enable |

## 11 x 17 inch print views

The [system PDF](../cad/wiring/v1-proof-el-01-overview-11x17.pdf) and the [motor PDF](../cad/wiring/v1-proof-el-05-both-wheels-11x17.pdf) each contain one sheet. Both use landscape orientation and 0.5 inch margins. Select 11 x 17 inch paper and print at 100% scale. The five-sheet atlas uses the same page size.

The print layout date is October 5, 2026. The source audit remains Rev B. EL-01 uses less vertical space. Text and circular symbols keep their proportions. EL-01 and EL-05 omit the dot grid for clear print output. Their website diagrams and PDFs use the same generated SVGs.

Follow the [export procedure](../cad/wiring/README.md) after each electrical change. The site build rejects exports that do not match their recorded source hashes.

## Diagram conventions

Colors identify the rail families or the signal families. The motor lead colors keep their documented function, and outlined white is encoder B. Dots show connected branches. Crossings without dots do not connect. Ground symbols share the common reference. Dashed component frames mark circuits or interfaces whose implementation remains undecided.

EL-01 shows individual conductors with global IDs and named endpoints. Those IDs refer to the searchable wire register. EL-05 labels wheel terminals without separate wire IDs. Search those terminal names in the same register.

IDs are references for the proposed harness. They do not establish released wire gauges, connector contacts or internal circuit designs. Functional blocks are not connector face views. EL-02–04 provide closer pin maps and implementation notes alongside the complete system drawing.

## Both motors and the wire register

The [two-wheel sheet](../cad/wiring/v1-proof-el-05-both-wheels.svg) shows both planned channels independently. Each motor has two switched power leads and four encoder leads. Each driver also needs its own power and ground, command signals, fault feedback, conditioned current feedback, mode straps and a current-limit setting network (TBD). Encoder A and B need separate conversion channels. The hardware gate supplies SLEEP to both drivers.

Match a conductor ID in the schematic to its source and destination in the [searchable register](../cad/wiring/v1-proof-wire-register.html). The [machine-readable endpoint and connection register](../cad/wiring/v1-proof-netlist.json) supports review and generation. These files describe proposed external wiring. They do not close any dashed internal interface or protection circuit. Both channels are planned, and the [inventory](parts-on-hand.md) records the actual received quantities.

## Sensor harness — source checked

The Pico 2 component side faces the viewer, with the Micro-USB at the top. Physical pins run 1–20 down the left and 40–21 down the right. GPIO numbers are different from physical pin numbers.

| Pico signal | Physical pin | SparkFun SEN-18020 pad |
| --- | --- | --- |
| GND | 18 | GND |
| 3V3(OUT) | 36 | 3V3 |
| GP15 / SPI1 MOSI | 20 | SDA / SDI |
| GP14 / SPI1 SCK | 19 | SCL |
| GP12 / SPI1 MISO | 16 | SDO |
| GP13 / chip-select | 17 | CS |
| GP16 / data-ready input | 21 | INT1 |

**Before SPI, open the 0x6B/0x6A address jumper and leave its selection pads unbridged.** We also recommend that you open both I2C pull-up traces. Keep the SCX and SDIX ground jumpers intact. Qwiic and the auxiliary SPI pads are unused. The main SPI connection uses the six-pad main header and INT1.

The drawing rotates the SparkFun component view clockwise 90 degrees. This puts the main pads on the left. Board outlines and pad spacing are proportional. Internal component graphics are simplified. Inspect the received board revision, labels and jumper state before you solder.

We independently compared these sources: [Raspberry Pi Pico 2 pinout](https://datasheets.raspberrypi.com/pico/Pico-2-Pinout.pdf), [SparkFun hardware overview](https://learn.sparkfun.com/tutorials/qwiic-6dof-lsm6dso-breakout-hookup-guide/hardware-overview), [SparkFun schematic](https://cdn.sparkfun.com/assets/3/1/6/b/c/SparkFun_Qwiic_6DoF_LSM6DSO_Schematic.pdf), and [SparkFun PCB layout](https://github.com/sparkfun/SparkFun_Qwiic_6DoF_LSM6DSO/blob/main/Hardware/SparkFun_6DoF_LSM6DSO.brd).

## Wheel harness — source checked

Each Pololu 4752 gearmotor needs its own DRV8874 driver. Red and black connect to OUT1 and OUT2. **Black is a switched motor lead.** Encoder green is GND, blue is regulated 5 V, yellow is A and white is B. A/B pass through non-inverted conversion to 3.3 V. The view orientation of the six-position 2.54 mm female connector and its mating harness remain to verify. We assign no arbitrary pin-1 number.

The drawing shows the DRV8874 driver component side up, in the orientation of the vendor. Feed the actuator power through VIN. VM is access to the reverse-protected motor bus. Ground PMODE and IMODE directly. SLEEP is active low and must come from the hardware gate. Each open-drain FAULT needs its own 3.3 V pull-up.

CS returns through an ADC protection and conditioning interface. The VREF network remains to select and to calibrate against the 2.5 A peak target. The default limit of the carrier is not the released Hux value. EN low brakes. SLEEP low sets the outputs to off.

| Interface | Left GPIO / physical pin | Right GPIO / physical pin |
| --- | --- | --- |
| Encoder A | GP2 / 4 | GP4 / 6 |
| Encoder B | GP3 / 5 | GP5 / 7 |
| EN / PWM | GP6 / 9 | GP8 / 11 |
| PH / direction | GP7 / 10 | GP9 / 12 |
| FAULT | GP11 / 15 | GP18 / 24 |
| CS via conditioning | GP26 / 31 | GP27 / 32 |

We independently compared these sources: [Pololu 4752](https://www.pololu.com/product/4752), [4035 carrier and pinout](https://www.pololu.com/product/4035), [carrier schematic](https://www.pololu.com/file/0J1862/drv887x-single-brushed-dc-motor-driver-carrier-schematic.pdf), and [TI DRV8874 datasheet, current regulation and fault modes](https://www.ti.com/lit/ds/symlink/drv8874.pdf). The GPIO assignments come from the [Hux hardware proposal](v1-proof-hardware.md#interfaces-that-must-be-built-correctly), not from installed firmware. Wheel direction and encoder sign need lifted-wheel checks.

## Power and servo interfaces — functional plan

The fused distribution splits before the physical actuator cut. The logic stays powered for the log. The cut removes the positive feed to both wheel drivers and to the 9 V servo branch. All grounds share a reference. High-current returns need deliberate physical routing. The regulator, fuse, wire, connector and energy-clamp choices are still open.

External regulated 5 V enters **VSYS, physical pin 39**, through a suitable Schottky isolation diode or a power-OR circuit. Do not assume that the onboard USB diode of the Pico 2 isolates an external regulator from USB backfeed. Feed the LSM6DSO IMU from 3V3(OUT). Qualify the loaded rail voltage and the power-off injection at all GPIO/ADC interfaces.

| Function | Proposed Pico endpoint |
| --- | --- |
| Wheel enable request into gate | GP10 / pin 14 |
| External watchdog heartbeat | GP22 / pin 29 |
| Servo UART1 TX / RX | GP20 / pin 26; GP21 / pin 27 |
| Servo transceiver direction, if supported | GP17 / pin 22 |
| Deliberate arm input | GP19 / pin 25 |
| Pack voltage via protected divider | GP28 / pin 34 |
| Optional UART0 manual link | GP0 / pin 1; GP1 / pin 2 |

The plan supplies the selected ST3215 servo (12 V variant) from a protected regulated 9 V supply. The mounted torque and duty at that voltage remain unmeasured. Both servos share a single half-duplex TTL DATA net with distinct IDs. The cable contact order, the bus voltage compatibility and the adapter remain unconfirmed. Separate Pico 2 TX/RX connect to a compatible directional interface. They are not tied together on the bus.

The proposed wheel watchdog gate does not itself cut servo power. EL-01 adds a proposed servo torque-cut switch driven by the gated hardware enable. Its circuit and failure behavior still need selection and powered tests. The physical actuator cut covers both branches.

We independently compared these sources: [Pico 2 datasheet, power and ADC guidance](https://datasheets.raspberrypi.com/pico/pico-2-datasheet.pdf), [Raspberry Pi SDK pin functions](https://www.raspberrypi.com/documentation/pico-sdk/hardware.html), [Waveshare ST3215 variants](https://www.waveshare.com/product/modules/st3215-servo.htm), and [Waveshare directional bus interface example](https://files.waveshare.com/upload/d/d3/Bus_servo_control_circuit.pdf). This example documents the interface principle and does not select a purchased adapter.

## What was double checked

Independent reviews compared the vendor documents, schematics and component-side images with the repository proposal. A second review checked the generated SVGs and the endpoint register: all 40 Pico 2 pins, seven sensor connections, both wheel GPIO allocations, the DRV8874 pad order and six motor lead functions. The automated generation rejects duplicate Pico 2 pin allocations and checks the SPI/UART/ADC physical pins. The visual review covers line endpoints, ground crossings, board proportions, legibility and the enlarged viewer of the site.

Rev B adds a conductor graph that checks terminal coverage and endpoint/net conflicts. It checks all 26 proposed GPIO endpoints, 12 motor cable leads and six servo leads. Geometry checks reject overlapping wires of different nets and endpoint touches between different nets. They also reject wires hidden inside component bodies. EL-01 checks that all branches of each drawn net join, including its rails and junctions.

These checks verify the drawing data. They cannot prove physical wiring or the behavior of a TBD circuit.

This is source verification, not a measured assembly pass. The [received inventory](parts-on-hand.md), [Pico bring-up record](checklists/2026-10-03-pico-bringup.md) and [electrical qualification checklist](checklists/electronics-bringup.md) keep their current status. Before we can release an assembly schematic, we must record these items: the fuse and wire ratings, the energy clamps, the ADC protection and the encoder conversion. We must also record the servo interface, the watchdog circuits, the harness contact orientation and the physical tests.

[cad/wiring/README.md](../cad/wiring/README.md) describes the editable drawing source and the reproducible exports. The [endpoint register](../cad/wiring/v1-proof-netlist.json) is a review aid, not a firmware implementation.

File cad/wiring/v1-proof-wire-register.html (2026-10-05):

HUX / V1-PROOF / EL-01 / REV B

# Every conductor and its endpoints

04 October 2026. The register follows the full system schematic. Circuit values, connector face views and wire sizes remain to select and test.

Electrical page · Full schematic · JSON connection data

Find a wire, component, GPIO or net

Wire | From terminal | To terminal | Electrical net
W001 | U1.SDO / SDO | P1.GP12 / GP12 / p16 | SPI_SDO
W002 | U1.CS / CS | P1.GP13 / GP13 / p17 | SPI_CS
W003 | U1.SCL / SCL | P1.GP14 / GP14 / p19 | SPI_SCL
W004 | U1.SDI / SDI | P1.GP15 / GP15 / p20 | SPI_SDI
W005 | U1.INT1 / INT1 | P1.GP16 / GP16 / p21 | SPI_INT1
W006 | JUSB.VBUS / VBUS | P1.USB_VBUS / VBUS | USB_VBUS
W007 | JUSB.D+ / D+ | P1.USB_D+ / D+ | USB_D+
W008 | JUSB.D- / D- | P1.USB_D- / D- | USB_D-
W009 | JUSB.GND / GND | P1.USB_GND / GND | GND
W010 | G0 / G0 | G1 / G1 | GND
W011 | GL1 / GL1 | GL2 / GL2 | GND
W012 | GR1 / GR1 | GR2 / GR2 | GND
W013 | 3R / 3R | 3E / 3E | 3V3
W014 | 5L / 5L | 5R / 5R | 5V
W015 | 9L / 9L | 9R / 9R | 9V
W016 | ACT_L / ACT_L | ACT_R / ACT_R | ACT_BUS
W017 | ACT_R / ACT_R | ACT_LOW / ACT_LOW | ACT_BUS
W018 | 3L / 3L | 3M / 3M | 3V3
W019 | 3M / 3M | 3R / 3R | 3V3
W020 | G_L / G_L | GL1 / GL1 | GND
W021 | GR2 / GR2 | G_R / G_R | GND
W022 | G_L / G_L | Gbottom_L / Gbottom_L | GND
W023 | G_R / G_R | Gbottom_R / Gbottom_R | GND
W024 | P1.3V3 / 3V3 OUT / p36 | 3R / 3R | 3V3
W025 | U1.3V3 / 3V3 | 3M / 3M | 3V3
W026 | U1.GND / GND | Gimu / Gimu | GND
W027 | P1.GND / GND / p38 | Gpi / Gpi | GND
W028 | DL.VIN / VIN | VIN_L / VIN_L | ACT_BUS
W029 | DL.OUT1 / OUT1 | ML.RED / RED / OUT1 | L_MOTOR_OUT1
W030 | DL.OUT2 / OUT2 | ML.BLACK / BLACK / OUT2 | L_MOTOR_OUT2
W031 | P1.GP6 / GP6 / p9 | DL.EN / EN | L_EN
W032 | P1.GP7 / GP7 / p10 | DL.PH / PH | L_PH
W033 | P1.GP11 / GP11 / p15 | DL.FAULT / FAULT | L_FAULT
W034 | DL.CS / CS | AL.IN / IN | L_CS
W035 | AL.OUT / OUT | P1.GP26 / GP26 / p31 | L_ADC_SAFE
W036 | AL.REF / 3V3 ref | ADCref_L / ADCref_L | 3V3
W037 | AL.GND / GND | ADCg_L / ADCg_L | GND
W038 | RFL.1 / pull-up TBD | RF3_L / RF3_L | 3V3
W039 | RFL.2 / pull-up TBD | FAULT_L / FAULT_L | L_FAULT
W040 | DG_L / DG_L | DGend_L / DGend_L | GND
W041 | DL.GND / GND | DGGND_L / DGGND_L | GND
W042 | DL.PMODE / PMODE | DGPMODE_L / DGPMODE_L | GND
W043 | DL.IMODE / IMODE | DGIMODE_L / DGIMODE_L | GND
W044 | DL.VREF / VREF | RVL.1 / TBD: calibrate | L_VREF
W045 | RVL.2 / TBD: calibrate | DGend_L / DGend_L | GND
W046 | DG_L / DG_L | GL1 / GL1 | GND
W047 | ML.GREEN / GREEN / GND | G_L / G_L | GND
W048 | ML.BLUE / BLUE / 5V | 5L / 5L | 5V
W049 | ML.YELLOW / YELLOW / A | BL.A_IN / A_IN | L_ENC_A5
W050 | ML.WHITE / WHITE / B | BL.B_IN / B_IN | L_ENC_B5
W051 | BL.A_OUT / A_OUT | P1.GP2 / GP2 / p4 | L_ENC_A_OUT
W052 | BL.B_OUT / B_OUT | P1.GP3 / GP3 / p5 | L_ENC_B_OUT
W053 | BL.3V3 / 3V3 | B3_L / B3_L | 3V3
W054 | BL.GND / GND | BG_L / BG_L | GND
W055 | DR.VIN / VIN | VIN_R / VIN_R | ACT_BUS
W056 | DR.OUT1 / OUT1 | MR.RED / RED / OUT1 | R_MOTOR_OUT1
W057 | DR.OUT2 / OUT2 | MR.BLACK / BLACK / OUT2 | R_MOTOR_OUT2
W058 | P1.GP8 / GP8 / p11 | DR.EN / EN | R_EN
W059 | P1.GP9 / GP9 / p12 | DR.PH / PH | R_PH
W060 | P1.GP18 / GP18 / p24 | DR.FAULT / FAULT | R_FAULT
W061 | DR.CS / CS | AR.IN / IN | R_CS
W062 | AR.OUT / OUT | P1.GP27 / GP27 / p32 | R_ADC_SAFE
W063 | AR.REF / 3V3 ref | ADCref_R / ADCref_R | 3V3
W064 | AR.GND / GND | ADCg_R / ADCg_R | GND
W065 | RFR.1 / pull-up TBD | RF3_R / RF3_R | 3V3
W066 | RFR.2 / pull-up TBD | FAULT_R / FAULT_R | R_FAULT
W067 | DG_R / DG_R | DGend_R / DGend_R | GND
W068 | DR.GND / GND | DGGND_R / DGGND_R | GND
W069 | DR.PMODE / PMODE | DGPMODE_R / DGPMODE_R | GND
W070 | DR.IMODE / IMODE | DGIMODE_R / DGIMODE_R | GND
W071 | DR.VREF / VREF | RVR.1 / TBD: calibrate | R_VREF
W072 | RVR.2 / TBD: calibrate | DGend_R / DGend_R | GND
W073 | DG_R / DG_R | GR2 / GR2 | GND
W074 | MR.GREEN / GREEN / GND | G_R / G_R | GND
W075 | MR.BLUE / BLUE / 5V | 5R / 5R | 5V
W076 | MR.YELLOW / YELLOW / A | BR.A_IN / A_IN | R_ENC_A5
W077 | MR.WHITE / WHITE / B | BR.B_IN / B_IN | R_ENC_B5
W078 | BR.A_OUT / A_OUT | P1.GP4 / GP4 / p6 | R_ENC_A_OUT
W079 | BR.B_OUT / B_OUT | P1.GP5 / GP5 / p7 | R_ENC_B_OUT
W080 | BR.3V3 / 3V3 | B3_R / B3_R | 3V3
W081 | BR.GND / GND | BG_R / BG_R | GND
W082 | P1.GP0 / GP0 / p1 | J7.RX / RX | UART0_TX
W083 | J7.TX / TX | P1.GP1 / GP1 / p2 | UART0_RX
W084 | J7.GND / GND | G_L / G_L | GND
W085 | J7.3V3 / 3V3 | J7V / J7V | 3V3
W086 | P1.GP19 / GP19 / p25 | ARM / ARM | ARM_N
W087 | RA.2 / 10k proposed | ARM / ARM | ARM_N
W088 | RA.1 / 10k proposed | RA3 / RA3 | 3V3
W089 | ARM / ARM | SW2.IN / IN | ARM_N
W090 | SW2.GND / GND | SWG / SWG | GND
W091 | P1.GP10 / GP10 / p14 | G1.REQUEST / REQUEST | ENABLE_REQUEST
W092 | P1.GP22 / GP22 / p29 | WD.HB / HB | HEARTBEAT
W093 | WD.HEALTH / HEALTH | G1.HEALTH / HEALTH | WD_HEALTH
W094 | 3L / 3L | CTRL3 / CTRL3 | 3V3
W095 | CTRL3 / CTRL3 | WD.3V3 / 3V3 | 3V3
W096 | CTRL3 / CTRL3 | G1.3V3 / 3V3 | 3V3
W097 | WD.GND / GND | GWD / GWD | GND
W098 | G1.GND / GND | GG / GG | GND
W099 | G1.OUT / OUT | EN / EN | HW_ENABLE
W100 | EN / EN | DL.SLEEP / SLEEP | HW_ENABLE
W101 | EN / EN | ENR / ENR | HW_ENABLE
W102 | ENR / ENR | DR.SLEEP / SLEEP | HW_ENABLE
W103 | D5.A / A ← 5V | 5D / 5D | 5V
W104 | D5.K / K → VSYS | P1.VSYS / VSYS / p39 | VSYS
W105 | P1.GP20 / GP20 / p26 | T1.TX_IN / TX_IN | SERVO_TX_IN
W106 | P1.GP21 / GP21 / p27 | T1.RX_OUT / RX_OUT | SERVO_RX_OUT
W107 | P1.GP17 / GP17 / p22 | T1.DIR / DIR | SERVO_DIR
W108 | 3E / 3E | T3 / T3 | 3V3
W109 | T3 / T3 | T1.3V3 / 3V3 | 3V3
W110 | T1.GND / GND | TG / TG | GND
W111 | T1.DATA / DATA | DATA / DATA | SERVO_DATA
W112 | SL.V+ / V+ | 9L / 9L | 9V
W113 | SL.DATA / DATA | DATA / DATA | SERVO_DATA
W114 | SL.GND / GND | SG_L / SG_L | GND
W115 | SR.V+ / V+ | 9R / 9R | 9V
W116 | SR.DATA / DATA | DATA / DATA | SERVO_DATA
W117 | SR.GND / GND | SG_R / SG_R | GND
W118 | BAT.+ / + | F1.IN / IN | PACK
W119 | F1.OUT / OUT | FUSED / FUSED | PACK_FUSED
W120 | FUSED / FUSED | V5.IN+ / IN+ | PACK_FUSED
W121 | FUSED / FUSED | SW1.IN+ / IN+ | PACK_FUSED
W122 | FUSED / FUSED | AP.IN / IN | PACK_FUSED
W123 | SW1.OUT+ / OUT+ | ACT_LOW / ACT_LOW | ACT_BUS
W124 | ACT_LOW / ACT_LOW | V9.IN+ / IN+ | ACT_BUS
W125 | V5.OUT+ / OUT+ | 5REG / 5REG | 5V
W126 | V9.OUT+ / OUT+ | QS.IN+ / IN+ | 9V_RAW
W127 | QS.OUT+ / OUT+ | 9R / 9R | 9V
W128 | ENR / ENR | QS.ENABLE / ENABLE | HW_ENABLE
W129 | T3 / T3 | QS.3V3 / 3V3 | 3V3
W130 | AP.REF / REF | APREF / APREF | 3V3
W131 | P1.AGND / AGND / p33 | AP.AGND / AGND | GND
W132 | AP.OUT / OUT | P1.GP28 / GP28 / p34 | PACK_ADC_SAFE
W133 | CTRL3 / CTRL3 | SW1.AUX_IN / AUX_IN | 3V3
W134 | SW1.AUX_OUT / AUX_OUT | KILL / KILL | KILL_OK
W135 | KILL / KILL | G1.KILL_OK / KILL_OK | KILL_OK
W136 | KILL / KILL | RK.1 / pull-down TBD | KILL_OK
W137 | RK.2 / pull-down TBD | RKG / RKG | GND
W138 | BAT.- / - | BAT-G / BAT-G | GND
W139 | V5.IN- / IN- | V5IN-G / V5IN-G | GND
W140 | V5.OUT- / OUT- | V5OUT-G / V5OUT-G | GND
W141 | AP.GND / GND | APGNDG / APGNDG | GND
W142 | V9.IN- / IN- | V9IN-G / V9IN-G | GND
W143 | V9.OUT- / OUT- | V9OUT-G / V9OUT-G | GND
W144 | QS.GND / GND | QSGNDG / QSGNDG | GND

Junction terminals and rails are drawn connection points. One register row is one conductor segment between named endpoints. USB rows are cable conductors, not bare GPIO connections.

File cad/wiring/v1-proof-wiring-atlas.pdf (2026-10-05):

# Complete system wiring

### U1 / SparkFun LSM6DSO

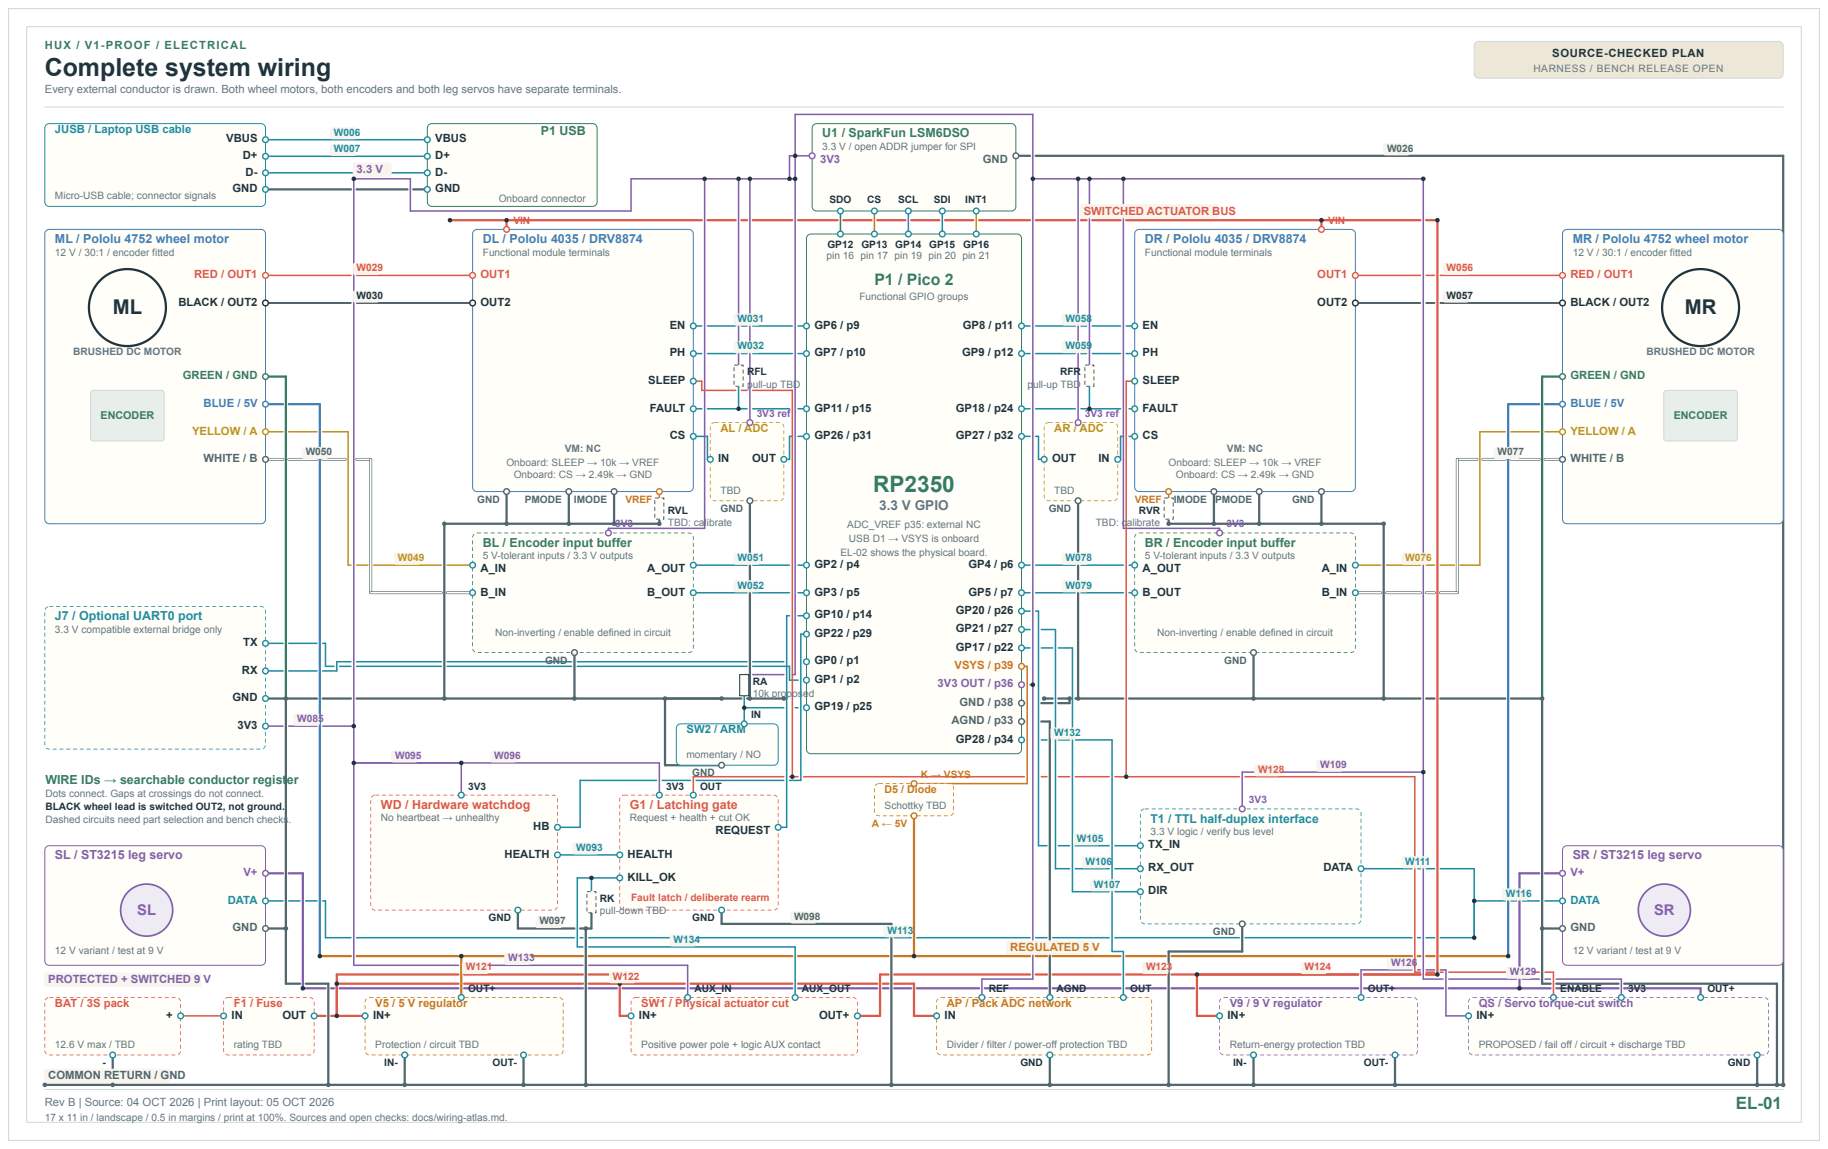
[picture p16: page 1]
P1 / Pico 2; Functional GPIO groups; 3.3 V GPIO; VSYS / p39 3V3 OUT / p36 GND / p38 AGND / p33; SDO; GP12 pin 16; GP13 pin 17; SCL; GP14 pin 19; SDI; GP15 pin 20; INT1; GP16 pin 21; GND; P1 USB; Onboard connector; VBUS; ENCODER; RED / OUT1; BLACK / OUT2; GREEN / GND; BLUE / 5V; YELLOW / A; WHITE / B; OUT2; SLEEP; FAULT; PMODE; IMODE; VREF; AL / ADC; TBD; OUT; 3V3 ref; RVL TBD: calibrate; A_OUT; B_OUT; OUT1; VIN; VREF IMODE; AR / ADC; RVR TBD: calibrate; RA 10k proposed; SW2 / ARM; HEALTH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

HUX / V1-PROOF / ELECTRICAL

SOURCE-CHECKED PLAN
HARNESS / BENCH RELEASE OPEN

Every external conductor is drawn. Both wheel motors, both encoders and both leg servos have separate terminals.

JUSB / Laptop USB cable

3.3 V / open ADDR jumper for SPI

Micro-USB cable; connector signals

SWITCHED ACTUATOR BUS

VIN
DL / Pololu 4035 / DRV8874
Functional module terminals
OUT1

ML / Pololu 4752 wheel motor
12 V / 30:1 / encoder fitted

DR / Pololu 4035 / DRV8874

MR / Pololu 4752 wheel motor
RED / OUT1

BRUSHED DC MOTOR

RFL
pull-up TBD

RFR

Onboard: SLEEP → 10k → VREF
Onboard: CS → 2.49k → GND

ADC_VREF p35: external NC
USB D1 → VSYS is onboard
EL-02 shows the physical board.

BL / Encoder input buffer
5 V-tolerant inputs / 3.3 V outputs

BR / Encoder input buffer
A_OUT
B_OUT

J7 / Optional UART0 port
3.3 V compatible external bridge only

Non-inverting / enable defined in circuit

momentary / NO
GND
G1 / Latching gate
Request + health + cut OK

WIRE IDs → searchable conductor register
Dots connect. Gaps at crossings do not connect.
BLACK wheel lead is switched OUT2, not ground.
Dashed circuits need part selection and bench checks.

WD / Hardware watchdog
No heartbeat → unhealthy

SL / ST3215 leg servo

SR / ST3215 leg servo

Fault latch / deliberate rearm
pull-down TBD

12 V variant / test at 9 V

SW1 / Physical actuator cut

AP / Pack ADC network

QS / Servo torque-cut switch

Protection / circuit TBD

Positive power pole + logic AUX contact

Divider / filter / power-off protection TBD

Return-energy protection TBD

PROPOSED / fail off / circuit + discharge TBD

COMMON RETURN / GND

Rev B | Source: 04 OCT 2026 | Print layout: 05 OCT 2026
17 x 11 in / landscape / 0.5 in margins / print at 100%. Sources and open checks: docs/wiring-atlas.md.

## H U X / V1 -P ROOF / ELE C T R I C A L

# Pico 2 + IMU connections

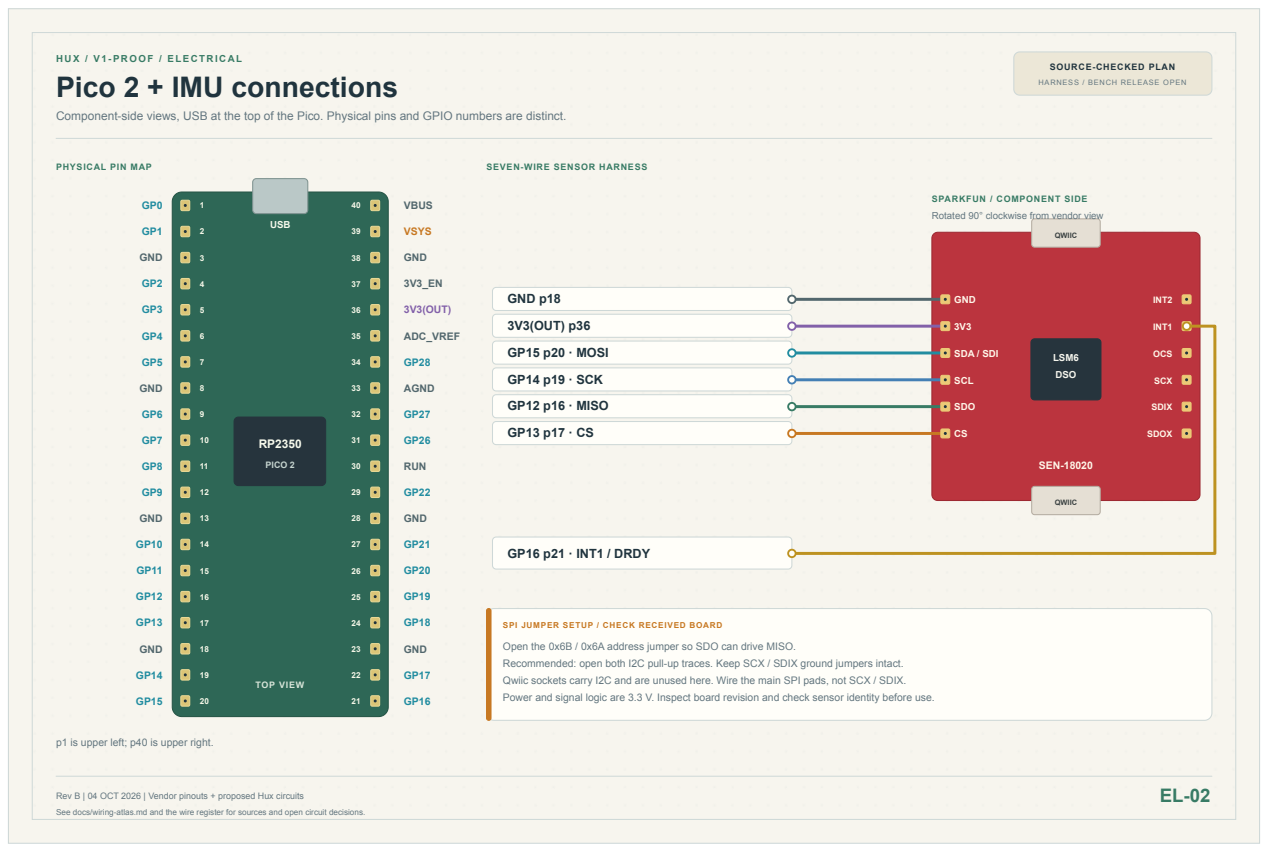
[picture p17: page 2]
USB; PICO 2; TOP VIEW; GND; 40 VBUS; 39 VSYS; 38 GND; 36 3V3(OUT); 35 ADC_VREF; 33 AGND; 30 RUN; 28 GND; 23 GND; QWIIC; LSM6 DSO; SEN-18020; GND p18; INT2; 3V3(OUT) p36; INT1; GP15 p20 · MOSI; SDA / SDI; OCS; GP14 p19 · SCK; SCL; SCX; GP12 p16 · MISO; SDO; SDIX; SDOX; GP16 p21 · INT1 / DRDY

SOURCE-CHECKED PLAN

HARNESS / BENCH RELEASE OPEN

Component-side views, USB at the top of the Pico. Physical pins and GPIO numbers are distinct.

PHYSICAL PIN MAP

SEVEN-WIRE SENSOR HARNESS

SPARKFUN / COMPONENT SIDE
Rotated 90° clockwise from vendor view

SPI JUMPER SETUP / CHECK RECEIVED BOARD
Open the 0x6B / 0x6A address jumper so SDO can drive MISO.
Recommended: open both I2C pull-up traces. Keep SCX / SDIX ground jumpers intact.
Qwiic sockets carry I2C and are unused here. Wire the main SPI pads, not SCX / SDIX.
Power and signal logic are 3.3 V. Inspect board revision and check sensor identity before use.

p1 is upper left; p40 is upper right.

Rev B | 04 OCT 2026 | Vendor pinouts + proposed Hux circuits
See docs/wiring-atlas.md and the wire register for sources and open circuit decisions.

## H U X / V1 -P ROOF / ELE C T R I C A L

# Wheel motor + encoder harness

One channel shown; repeat for the other wheel using the assignment table. Colors match the motor leads.

### SOURCE-CHECKED PLAN

HARNESS / BENCH RELEASE OPEN

### Rev B | 04 OCT 2026 | Vendor pinouts + proposed Hux circuits

EL-03

PICO / PROPOSED OUTPUTS

# 3.3 V command signals

Use the left / right GPIO table below.

### POLOLU 4035 / TOP VIEW

DRV
8874
VM | VIN
GND | GND
EN / IN1 | OUT1
PH / IN2 | OUT2
PMODE | IMODE
SLEEP | FAULT
VREF | CS

# EN / PWM

# PH / direction

# Gated SLEEP

### VM: leave unused

## PMODE + IMODE directly to GND

## Switched bus +

POLOLU 4752 / MOTOR LEADS

# 12 V, 30:1 gearmotor

## RED lead → OUT1 BLACK lead → OUT2

Both motor leads are switched.

## RED

## BLACK ≠ GND

FAULT / CURRENT INPUTS

# Return to Pico via protection

## FAULT → GP11 / GP18; 3.3 V pull-ups CS → GP26 / GP27 via protection TBD

VREF network TBD: set + measure 2.5 A peak | Latch faults; deliberate rearm required.

4752 / ENCODER LEADS

# Four-wire feedback harness

## GREEN → common GND BLUE → regulated 5 V YELLOW → channel A WHITE → channel B

Connector orientation: verify by color.

REQUIRED INTERFACE / PART TBD

# 5 V → 3.3 V level conversion

## Four input channels for both wheels Use a translator suitable for push-pull

quadrature outputs; check power-off state. No direct 5 V signals into Pico GPIO.

### GND / GREEN

### 5 V / BLUE

### A / YELLOW

### B / WHITE

PICO / LEFT AND RIGHT CHANNELS

# Proposed pin assignments

Function | Left | Right
Encoder A | GP2 | GP4
Encoder B | GP3 | GP5
EN / PH | GP6/7 | GP8/9
FAULT | GP11 | GP18
CS / ADC | GP26 | GP27

EN low = brake. SLEEP low = outputs off / coast.
2.5 A peak / 1.2 A RMS are Hux qualification targets, not tested settings.

## H U X / V1 -P ROOF / ELE C T R I C A L

# Power distribution + servo bus

Functional interface drawing: regulator, clamp, fuse, enable-gate and bus-adapter circuits remain to select.

### SOURCE-CHECKED PLAN

HARNESS / BENCH RELEASE OPEN

### Rev B | 04 OCT 2026 | Vendor pinouts + proposed Hux circuits

EL-04

BATTERY / UNCONFIRMED

# 3S pack

## Up to 12.6 V charged

PROTECTION / TBD

# Main fuse

## Fuse / wire / connector sizing

PHYSICAL CUT / TBD

# Actuator power cut

## Opens positive feed to all actuators

WHEELS / ×2

# DRV8874 VIN

## Use VIN; VM is protected bus access

UNSWITCHED LOGIC BRANCH / TBD

# Protected 5 V regulator

## Branch protection + return-energy handling Feeds both encoder BLUE leads at 5 V

USB + EXTERNAL POWER / TBD

# Schottky diode / power ORing

## External 5 V → isolation → VSYS p39 Check loaded voltage and USB backfeed

CONTROLLER / LOGIC ONLY

# Pico 2 power + ADC

## 3V3(OUT) p36 → IMU + interface logic GP28 p34 ← protected pack divider

### VSYS p39

SWITCHED SERVO BRANCH / TBD

# 9 V regulator + protection

## About 6 A short-peak sizing target Define an energy sink / clamp

Qualify voltage / heat at load.

TWO ST3215 / 12 V VARIANT

# Shared half-duplex bus

## Supply: protected regulated 9 V GND: common return DATA: single TTL bus

Assign different servo IDs. Confirm cable contact order.

## 9 V

SERVO INTERFACE / ADAPTER TBD

# 3.3 V-compatible transceiver

## GP20 p26 TX → interface TX input GP21 p27 RX ← interface RX output GP17 p22 → direction (if supported)

## TTL DATA

ENABLE + WATCHDOG BOUNDARY

## GP10 p14 + GP22 p29 → hardware gate

Gate output → BOTH wheel SLEEP pins. Servo torque-cut circuit: proposed in EL-01. Physical cut must remove wheel + servo power.

## COMMON GND / RETURNS

All GND symbols join this reference. Route high-current returns away from sensor / MCU wiring.

MEASUREMENT INTERFACES / TBD
Pack divider + ADC protection → GP28. Both CS inputs need ADC protection. Check input range and power-off injection.

# Both wheel motors — every wire

### PL / Pico 2 / LEFT

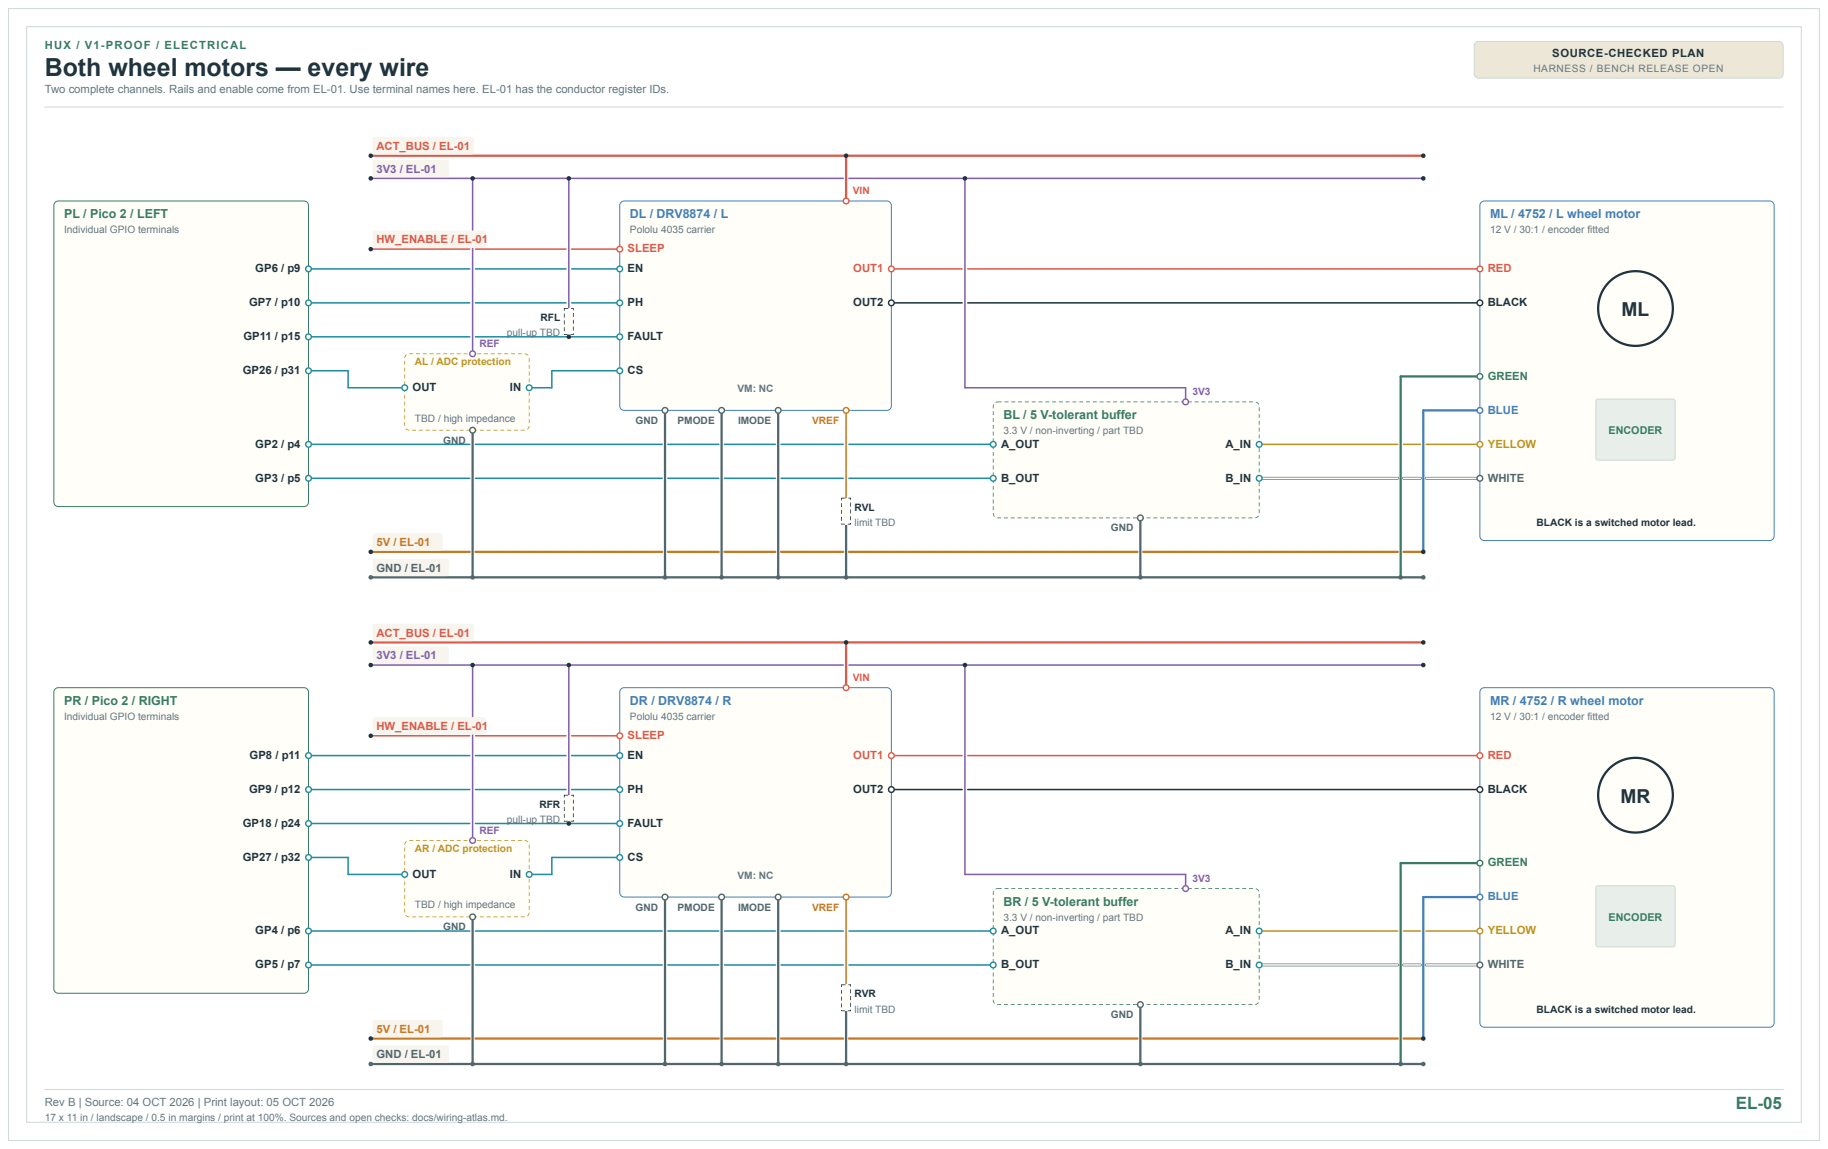
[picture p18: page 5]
DL / DRV8874 / L; Pololu 4035 carrier; ENCODER; FAULT; OUT; OUT1; OUT2; RED; BLACK; GREEN; BLUE; YELLOW; WHITE; B_OUT; ACT_BUS / EL-01; GND / EL-01; VIN; GND; PMODE; IMODE; SLEEP; HW_ENABLE / EL-01; RFL; VREF; RVL limit TBD; DR / DRV8874 / R; RVR limit TBD

HUX / V1-PROOF / ELECTRICAL

SOURCE-CHECKED PLAN
HARNESS / BENCH RELEASE OPEN

Two complete channels. Rails and enable come from EL-01. Use terminal names here. EL-01 has the conductor register IDs.

ML / 4752 / L wheel motor
12 V / 30:1 / encoder fitted

Individual GPIO terminals

pull-up TBD
REF

AL / ADC protection

BL / 5 V-tolerant buffer
3.3 V / non-inverting / part TBD
A_OUT

TBD / high impedance

BLACK is a switched motor lead.

PR / Pico 2 / RIGHT

MR / 4752 / R wheel motor

RFR

AR / ADC protection

BR / 5 V-tolerant buffer

Rev B | Source: 04 OCT 2026 | Print layout: 05 OCT 2026
17 x 11 in / landscape / 0.5 in margins / print at 100%. Sources and open checks: docs/wiring-atlas.md.

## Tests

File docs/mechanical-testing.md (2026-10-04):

# Mechanical testing — layout and dated results

Open the [living mechanical test page](../tools/living-drawings/mechanical-tests.html) for the movable linkage diagram, the R01 print render, the test steps and the chronological record. Start with the [first passive fit session](checklists/2026-10-02-mechanical-fit.md). The record shows the receipt and the 3D printing of the parts on October 2, 2026. There is no reported measured test result.

## Read the layout

The diagram uses the R01 parallelogram: two 110 mm links, 40 mm fixed/carrier pivot separation, a 30° neutral and a 15–45° design range. Move the angle control to compare the axle positions. The end view shows 2 mm lower-link and 12 mm upper-link spacers at both ends of their respective links. Confirm the printed revision before you use that stack.

The 100 mm circle is a wheel envelope. The motor placement, hubs, bearings and powered mounts still need measurements and detail design.

The current Blender render shows a passive assembly at neutral. It is a design render, not a photograph of completed hardware. Use it to understand the arrangement. The actual fastener stacks and printed fits remain to record. [Canonical R01 assembly guide](../cad/prints/v1-proof-r01/README.md).

## Record each session

1. Select a step and enter the actual session date/time, measurements, outcome, observations and photo/log references. Keep failed trials. A passed trial needs both measurements and evidence. It does not close the whole stage or qualify balance.
2. The notes save in this browser on this device and appear in the dated timeline as **device drafts**. Export a JSON copy to keep or transfer them. The backup offers both a file download and selectable text. Import merges the records that match and does not replace the entries that conflict. Keep the exported file with the photos/logs that it refers to. The form does not upload results or photographs to the public site.
3. To make results part of the **shared project history**, bring the session measurements and evidence back to this chat. Record the reviewed trial in a dated repository session. Then append a `kind: test` event to `tools/living-drawings/mechanical-tests-data.json` with its `stepId`, `outcome`, `measurements`, `notes` and `sourcePaths` that point to that evidence. Keep the user’s actual test date separate from the date of the record.
4. Update the shared step status and `plan-data.json` only when the step meets its whole evidence gate. A local passed trial is not a published milestone pass. Rebuild, check and publish with the [existing site workflow](site-maintenance.md).

The shared timeline starts with the preparation and the user’s report of the arrival and the printed parts. Planned tests have no invented completion dates. Device drafts appear next to the shared records with explicit labels and never change the published gates.

## Progression

Inspect and measure → passive assembly → hand sweep → motor/wheel packaging → repeatability. These checks use disconnected power and the passive mockup. Restrained wheel tests, supported driven-leg commissioning and measured load/duty work obey the [bench plan](one-leg-bench.md), its supported mounts and its electrical/fault gates. The prints alone have no applied-load qualification.

[Neutral layout sheet](../cad/layouts/mechanical-test-bench.svg) · [Full session template](checklists/one-leg-bench-session.md) · [Physical acceptance checklist](checklists/mechanical-v1.md).

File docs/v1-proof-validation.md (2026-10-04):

# V1-PROOF mobility acceptance protocol

These are **physical tests to do**, not completed results. The [simulation report](v1-proof-simulation.md) records synthetic evidence separately. All physical boxes remain open. The reliability that the user requested becomes repeatable, logged trials at the final measured mass. We infer no statistical real-world reliability from simulated seeds.

## Conditions and records

Use a catch frame or a slack overhead catch, a clear runoff, an accessible hard kill and pinned 30° legs. Successful runs have no catch/skid contact, no human aid and no reset. Measure the paths and the angles with floor marks and a calibrated external camera. Encoders alone cannot certify slip-free distance. Record the firmware/config hash, mass, CoM, tire condition, floor, battery loaded voltage, motor/driver temperature and timestamped control logs.

Do the tests on two representative dry indoor floors. Do them at the nominal battery voltage and again at the approved loaded minimum of the actual pack. The 9.9 V input of the simulation is a sizing condition, not a universal battery cutoff. Start each new condition with low-power supported tuning. Before the grade trials, adjust the battery/frame placement to within ±2 mm sprung fore/aft CoM offset at pinned 30°. Then measure the actual pitch trim.

The broad simulation kept a near −4 mm corner that missed its settling gate.

## Mobility

| Trial | Target and permitted error | Repeats per floor/voltage condition |
| --- | --- | --- |
| Stand | 60 s; within 0.12 m of the start, pitch within ±3° of calibrated trim after settling | 10 starts, at least 9 successful |
| Forward | 2 m at 0.25 m/s, stop and hold; endpoint error ≤0.12 m, heading error ≤5° | 10 consecutive successful runs |
| Reverse | Same, commanded −0.25 m/s | 10 consecutive |
| Left / right arc | 90° each, 0.20 m/s and 0.40 rad/s; endpoint ≤0.12 m, heading ≤5° | 10 consecutive per direction |
| Turn in place | Full 360° both ways, ≤0.60 rad/s; drift ≤0.12 m, heading ≤5° | 10 consecutive per direction |
| Combined sequence | Forward, stop, reverse, left, right, both pivots, stop | Five consecutive sequences |

Ramp the travel at ≤0.35 m/s² and the yaw at ≤1.2 rad/s². Limit the commanded speed to 0.25 m/s for this release. 0.5 m/s remains a later qualification target. During recovery, make up to 0.65 m/s wheel-ground travel available in the clear fixture. This is transient catch authority, not a manual cruise speed. Pitch stabilization has priority over travel/yaw.

Qualify the excessive-tilt, overspeed and current fault thresholds in the fixture before the free trials.

After each maneuver, the robot must hold one uninterrupted second with speed <0.06 m/s, yaw rate <0.12 rad/s and pitch error <3°. A fall, a missed path, a sustained oscillation, excessive current, support contact or an unplanned disable fails that run. A repeat of a failed run does not erase it. Keep all the logs and restart the consecutive series after a documented fix.

## Pushes and shoves

Use a compliant, instrumented fixture or a calibrated pendulum with a load cell. Integrate the measured contact force over time. The initial momentum of a pendulum alone does not establish the delivered impulse, because the pendulum can rebound. Apply the push at **0.20 m above the floor**, near the body centerline. Do the test for both signs along and across the axle direction.

| Direction | Initial qualifying impulse | Pulse-duration targets | Pass |
| --- | --- | --- | --- |
| Forward / rearward | **0.8 N·s** | 0.20 s (~4 N average) and 0.05 s (~16 N) | Settle within 3 s; catch travel ≤0.35 m; final offset ≤0.12 m |
| Lateral, both sides | **0.4 N·s** | 0.20 s (~2 N) and 0.05 s (~8 N) | Same; no sustained contact loss or roll excursion above 10° |
| While driving forward | 0.8 N·s forward at 0.25 m/s | 0.20 s | Complete the route, ≤0.20 m endpoint error, then settle |

Start below these impulses and increase them gradually in the fixture. Complete ten consecutive repetitions per sign/duration at the nominal mass. Then repeat the qualifying set at the final mass and low voltage. The pitch excursion from trim must remain ≤12°. The modeled motor peaks must remain ≤2.5 A and the session RMS ≤1.2 A per motor, subject to stricter measured thermal limits. Qualify the higher current pulse duration independently on the bench.

Strong human shoves are **not** a promised capability. The study includes 4 N·s fore/aft and lateral failure cases at 0.24 m height. A change of pulse duration, height, contact point or friction changes the result even at equal impulse. Off-axis torsion impulses, unpredictable collisions and recovery from a one-wheel stance remain unqualified.

## Uneven indoor surfaces

At **0.15 m/s**, do a straight ascent and descent of a 3° grade and a traverse of ±3° cross-slopes. Also do a 5 mm smooth bump with a 300 mm transition length and the same bump under one wheel. Then do a 3 mm square floor seam. Do ten consecutive traversals of each fixture at the final mass and low voltage. Use the same stop/path criteria (grade endpoint allowance 0.15 m). There must be no body contact, roll ≤10°, and no wheel separation longer than 80 ms.

Use high-frame-rate video for the contact condition. Simulated geometric contact is not a physical load measurement.

These are separate intended test fixtures. Simultaneous shove + turn + bump combinations are not qualified. No loose gravel, rugs, holes, curbs, 20 mm thresholds or stairs. Powered leg level control and disturbance recovery during a height change need a later dynamic model and physical trials.

## Duty, faults and next-version release

- [ ] Repeat the ten-minute mixed balance/drive/height session within the measured temperature and electrical limits, with controlled stops and both steering directions. The current simulator has no thermal model. Short runs cannot clear this gate.
- [ ] Do tests of the hard kill, stale command >250 ms, stale IMU/encoder, missed deadlines, undervoltage, reset and driver fault. A deliberate rearm is necessary. Do a test of power removal in the catch fixture.
- [ ] Complete ten powered low/high/low cycles over the measured qualified range. Target ≥25 mm height change. This is a separate gate from pinned-leg mobility.
- [ ] Keep the total mass ≤3.0 kg and the actual all-in new cash < $1,000.
- [ ] Replace the simulation assumptions with measured motor, delay, inertia, friction and backlash data. Rerun the complete matrix and investigate every failure.
- [ ] Archive the trial CSVs/video references and the failure counts with the firmware/model hashes before you add V2 payload, compute, cameras or terrain requirements.

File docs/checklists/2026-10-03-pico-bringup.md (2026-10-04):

# Pico 2 USB bring-up — opened 2026-10-03

**Received:** one Pico 2 with yellow pre-soldered headers and one LSM6DSO IMU. We recorded the user confirmation on October 3. Both parts are untested. This confirmation supersedes the screenshot delivery estimate.

The October 2 Amazon order total is **$30.58**. The order does not show the item prices, the shipping, the tax or the payment date. [Inventory](../parts-on-hand.md) · [Order evidence](../purchases.md).

## First check: USB and the onboard LED

Place the board on a nonconductive surface. For this board-only check, keep the motor drivers, servos, battery and external GPIO wires disconnected. Use a **Micro-USB data cable** to connect the board to the computer.

1. Hold **BOOTSEL** while you connect the Pico 2 to USB. Then release **BOOTSEL**.
2. Make sure that a drive named **RP2350** appears. Pico 2 uses this name. The first-generation Pico uses RPI-RP2. If no drive appears, try again with a known data cable and USB port.
3. Download the official **Blink UF2** from the link under [Raspberry Pi's C/C++ SDK first binaries](https://www.raspberrypi.com/documentation/microcontrollers/c_sdk.html#your-first-binaries). Raspberry Pi documents that this download supports all Pico variants.
4. Copy the UF2 to **RP2350**. Make sure that the board reboots, the drive disappears and the onboard LED blinks.
5. Optional: repeat the step with the official **Hello World UF2** from the same page. This step is a check of the USB serial output. On macOS, compare the device list before and after connection to identify the new `/dev/cu.usbmodem…` device. Record the exact port and the observed output.

The Hux firmware target remains **C/C++ with `PICO_BOARD=pico2`**. These vendor examples are checks of the board and the USB path. The Hux firmware is not implemented yet. [Software contract](../software.md).

## Check the received IMU

The received sensor is the **SparkFun LSM6DSO Qwiic (manufacturer model SEN-18020)**. It replaces the earlier Adafruit LSM6DSOX selection. Do a check of the received label and the board revision. Use the LSM6DSO register definitions and initialization. Make the sensor identification a part of the bring-up.

SparkFun specifies **3.3 V operation**, SPI and I2C support, and exposed interrupt pins. Power this breakout from Pico 2 **3V3(OUT)** and GND. Keep its power and logic at 3.3 V. The Qwiic connectors carry I2C. The proposed Hux SPI connection uses the main SPI pads of the breakout and a separate interrupt wire. Before you solder, compare the exact pad/jumper configuration with the received board and the [SparkFun schematic](https://cdn.sparkfun.com/assets/3/1/6/b/c/SparkFun_Qwiic_6DoF_LSM6DSO_Schematic.pdf).

The [source-checked EL-02 wiring sheet](../../cad/wiring/v1-proof-el-02-pico-imu.svg) adds the physical Pico 2 pin numbers and the component-side pad view. **Open the 0x6B/0x6A address jumper before SPI.** Leave the SDO address-selection pads unbridged. We also recommend that you open both separate I2C pull-up traces. Keep the SCX/SDIX ground jumpers intact.

The main MOSI pad is labeled **SDA / SDI**. The main clock pad is labeled **SCL**. Inspect the received revision first. [SparkFun jumper instructions](https://learn.sparkfun.com/tutorials/qwiic-6dof-lsm6dso-breakout-hookup-guide/hardware-overview) · [Wiring verification record](../wiring-atlas.md).

| Proposed Pico signal | IMU function |
| --- | --- |
| GP12 | Main SPI MISO / SDO |
| GP13 | Main SPI chip-select / CS |
| GP14 | Main SPI clock / SCK |
| GP15 | Main SPI MOSI / SDI |
| GP16 | INT1, configured for data-ready |

This table keeps the [proposed GPIO allocation](../v1-proof-hardware.md#interfaces-that-must-be-built-correctly). Before balance control, start with the raw sensor readback, the stationary bias log and the axis/sign checks. The ±4 g, ±500°/s, 833 Hz sensor settings and the 500 Hz control loop remain qualification targets. [SparkFun specifications](https://www.sparkfun.com/sparkfun-6-degrees-of-freedom-breakout-lsm6dso-qwiic.html) · [ST LSM6DSO datasheet, hosted by SparkFun](https://cdn.sparkfun.com/assets/c/f/9/d/1/lsm6dso_datasheet.pdf).

## Session record — results pending

- [ ] Record the board markings, the header condition and any visible damage.
- [ ] Record the BOOTSEL drive enumeration: cable/port, host and observed drive name.
- [ ] Record the Blink UF2 source and the observed LED behavior.
- [ ] Record the optional USB serial port, the UF2 source and the actual output.
- [ ] Record the received IMU label, board revision, condition and connection check.
- [ ] After the firmware exists, record the IMU identity, raw readings, stationary bias, axis signs and measured timing.

**Observed results:** none recorded. The delivery opens this checklist. The delivery does not complete a firmware, sensor or powered-motion gate.

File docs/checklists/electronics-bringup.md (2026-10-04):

# V1-PROOF electronics checklist

**2026-10-03:** one Pico 2 is received. The LSM6DSO IMU is also received and untested. Start the [USB board check](2026-10-03-pico-bringup.md). Confirm the IMU and the remaining power/interfaces separately.

- [ ] Confirm the board/IMU, the radio plus transmitter or alternative manual link, the pack and the charger.
- [ ] Map the available pins/timers for the encoders, drivers, IMU, manual input and later servos.
- [ ] Do a check of the logic levels, the encoder scaling and the default-disabled wheel drivers.
- [ ] Add a fuse to one wheel. Restrain that wheel. Do a check of the direction, the encoder sign and the fault inputs.
- [ ] Measure the lowered hardware current limit. Qualify the 2.5 A short peak / 1.2 A RMS initial limits. Qualify the actual thermal behavior.
- [ ] Before you add the second wheel, do a check of the kill, watchdog, reset and stale-input drive disable.
- [ ] Do a test of the full/low battery voltage, the braking transients and the logic brownout margin.
- [ ] Do a test of both wheel channels with pinned legs in a catch frame.
- [ ] Add the correct servo variant, a suitable protected rail and the half-duplex/PWM interface. Make sure that simultaneous demand causes no MCU resets.
- [ ] Confirm that the manual kill works without laptop/companion software.

Obey [electronics](../electronics.md). All purchases remain inside the [shared budget](../bom.md).

## Revision B mobility gates

- [ ] Obey the [selected hardware and interface decisions](../v1-proof-hardware.md).
- [ ] Complete the [physical mobility/disturbance protocol](../v1-proof-validation.md). Include reverse travel, both arcs, both pivots, pulses and uneven fixtures.
- [ ] Record the measured CoM/inertia, motor response, current, latency, traction and backlash. Run the simulation again with those values.
- [ ] Retain the failures and the logs. Simulated passes do not close physical acceptance boxes.

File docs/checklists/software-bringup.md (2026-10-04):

# V1-PROOF software checklist

**2026-10-03:** the Pico 2 is received and untested. Start the [board-only USB/LED checklist](2026-10-03-pico-bringup.md). The received LSM6DSO IMU replaces the earlier LSM6DSOX selection. The sensor firmware and the qualification remain open.

- [ ] Blink/log on the available board. Identify the exact firmware/toolchain and the license choices.
- [ ] Calibrate and timestamp the IMU. Read the signed wheel encoders and the battery/current feedback.
- [ ] Measure the 500 Hz control-loop timing under the maximum intended log and input load.
- [ ] Implement `DISARMED`, `BALANCE`, `DRIVE`, latched `FAULT` and deliberate rearm.
- [ ] Do a test of stale commands (>250 ms), stale critical sensors, deadlines, reset and manual kill in the supported fixture.
- [ ] Adapt conventional balance control. Before you enable the closed loop, do a check of the polarity at low power.
- [ ] Tune the pinned-leg balance. Then tune the bounded speed/yaw with saturation protection.
- [ ] Log the physical trials. Compare them with the [finish line](../v1-proof.md#finish-line).
- [ ] Measure the pose-dependent pitch trim. Then add slow synchronized leg commands in `BALANCE`.
- [ ] Complete the ten-minute mixed session. Retain the faults/current/voltage/timing logs.

The host-side tests of the model are not evidence of a firmware implementation or a hardware pass.

## Revision B mobility gates

- [ ] Obey the [selected hardware and interface decisions](../v1-proof-hardware.md).
- [ ] Complete the [physical mobility/disturbance protocol](../v1-proof-validation.md). Include reverse travel, both arcs, both pivots, pulses and uneven fixtures.
- [ ] Record the measured CoM/inertia, motor response, current, latency, traction and backlash. Run the simulation again with those values.
- [ ] Retain the failures and the logs. Simulated passes do not close physical acceptance boxes.

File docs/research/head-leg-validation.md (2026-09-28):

> **PARKED STAIR-V1 — 2026-09-28.** This is historical research, not an active requirement, BOM or build gate. [V1-PROOF](../v1-proof.md) governs current work.

# Engineering verification — 2026-09-28

Revision: **2026-09-28-B**. Input SHA-256: `3aef03b21d75b8c224e416facf1859d6a5627259db956ccc661751a9979dd252`.

- `python3 tools/engineering/review.py --write` completed with the stored results. The preferred candidate uses 241.3 mm links, H1-B and a 120 mm stepping track. All `release` flags remain false.
- `python3 tools/engineering/test_review.py`: **13 checks passed**. Coverage includes mass/inertia translation, battery/COM sensitivity, enclosure fit, exact split-offset FK/IK, unreachable targets, gravity virtual work, lateral mirroring, contact sequencing, CAN/height budgets, moving width, continuous segment/box distance and the rejected aft motor package.
- `npm test` in `tools/living-drawings`: **passed**, including the engineering checks, 200 legacy spatial FK/IK cases, 402 projection frames, assumption/frontal checks and the Rapier regression suite. Its old stair candidate remains deliberately rejected; the short-hop regression does not prove controlled support.
- Python compilation and JavaScript syntax checks passed. `git diff --check` passed.
- Stored head properties agree with the current input. Regenerating SVG, HTML and BOM from the stored results produces identical hashes. Revised Markdown local-link targets exist.
- H1 SVG and the engineering page were visually inspected. This checks presentation, not manufacturing fit.

Preferred candidate: 91 connected poses plus 810 interpolated samples; no reach, limited-envelope or width-gate flags. The heavier-head case also passes those screens. Peak nominal gravity roll/pitch/knee torque: 6.61 / 3.92 / 7.89 N·m. Maximum modeled nominal span: 355.44 mm, leaving only 0.16 mm to the nominal width bound.

**Not verified:** real ankle carrier, exact component SKUs, complete inter-part swept solids, service/harness access, structural allowables, smooth timed dynamics, real contact footprint/traction, installed thermal duty, current/regen, firmware, single-leg support or a physical step. No purchases or fabrication release were made. Steve subsequently authorized committing and pushing the review to `main`.

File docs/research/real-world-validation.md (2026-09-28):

> **PARKED STAIR-V1 — 2026-09-28.** This is historical research, not an active requirement, BOM or build gate. [V1-PROOF](../v1-proof.md) governs current work.

# Hux: real-world assumptions review

> **2026-09-28:** historical study. Current head/leg dimensions, procurement and support gates are in [the engineering review](../head-and-leg-review.md). No components have been purchased; older order/selection claims are superseded.

**Historical baseline audit.** The findings below describe the pre-correction model at the commit named here. [Implemented corrections](model-corrections.md) and [current sandbox results](sim-sandbox.md) supersede its descriptions of the live code. Running the commands now tests the corrected model; the saved baseline output remains unchanged.

Reviewed **2026-09-23**, against commit `3b239a63b7beefca391781283c992a7378c15405`. No measured robot, motor characterization, or finished CAD was available. Numbers use the repository's **6 kg example**, not a measured mass. Recommendations are research findings, not new hardware decisions.

**Verdict:** the wheeled-biped concept is credible, and the basic planar kinematics check out. **The present drawings do not establish a buildable stair gait.** The combined side/front trajectory exceeds available spatial reach; single-wheel balance remains unsuccessful in the sandbox; and the stair calculation reports loads above proposed actuator limits while passing its self-test. Resolve these before using the animation for fabrication or actuator selection.

Reproduce the review:

```sh
node tools/living-drawings/assumption-audit.js
cd tools/living-drawings
npm test
```

The audit needs only Node. The simulation test needs the pinned Rapier dependency. [Audit source](../../tools/living-drawings/assumption-audit.js), [calculated results](assumption-audit-results.json), and [baseline test output](assumption-baseline-tests.txt) are included. Audit exit status checks arithmetic consistency; `designChecks` explicitly records failing design assumptions. A successful process exit is not a robot acceptance test.

## What is supported

| Assumption | Checked result | Meaning |
| --- | --- | --- |
| 6″ wheel, two 7.5″ links, 6″ body above hip | 24″ full height; 16.8″ hip height at 92% extension | Consistent planar, upright envelope; not a spatial clearance proof |
| Wheel placement one design step ahead/up | Hip-to-raised-axle distance 10.43″, leaving 4.57″ planar reach | Endpoint reachable; transferring the body is harder |
| Forward/inverse kinematics and torque Jacobian | 20 configurations agree with independent finite-difference virtual work | Correct algebra for the modeled two-link chain |
| Knee leverage at 92% extension | 2.94″ offset; 4.39 N·m for an ideal 6 kg point load on one leg, 2.20 per knee on two legs | Useful initial sizing; distributed mass and acceleration change it |
| Whole-robot tipping moment with CoM centered as one wheel unloads | 9.53 N·m about the planted contact | Correct gravity moment; not automatically the hip actuator torque |
| Wheel speeds | 63 / 188 / 376 rpm at 0.5 / 1.5 / 3 m/s | Consistent with a 6″ rolling diameter |
| Flat-floor sandbox | Existing suite passes; 75% ride height holds with ~3.16 N·m per knee | Evidence about this idealized model, not hardware |

The Jacobian/virtual-work method is standard; see [Modern Robotics, open-chain statics](https://modernrobotics.northwestern.edu/nu-gm-book-resource/5-2-statics-of-open-chains/). These numerical checks were calculated locally.

## 1. Geometry: the front and side views cannot both describe this mechanism

In [`kin.js`](../../tools/living-drawings/kin.js), `solveLegs()` solves sagittal geometry; `frontView()` independently translates the body laterally without reducing sagittal reach. At **3.289 s**, during the rear-wheel shove, the drawn left hip-to-axle separation is:

```text
fore/aft     5.718″
vertical   13.551″
lateral     7.350″
distance = sqrt(5.718² + 13.551² + 7.350²) = 16.442″
```

Even allowing the sandbox's **0.975″ lateral axle spacer** to point in any direction, the triangle inequality permits at most **7.5 + 7.5 + 0.975 = 15.975″**. The pose exceeds that generous bound by **0.467″**. The actual perpendicular spacer arrangement is more restrictive. This proves an inconsistency in the combined drawings; it does not prove that no alternative trajectory can work.

**Required correction:** solve hip roll, hip pitch, knee, body pose, and axle offset in one spatial chain. Regenerate all views from it. Recalculate reach during weight shifts, wheel lift, and unequal tread heights, including wheel camber and changing contact location.

Other geometry findings:

- The stair path folds the leading knee to **162.36°**, beyond the sandbox's **2.7 rad / 154.70°** soft stop. Harmonize joint travel, stops, cables, and collision geometry.
- The sampled trailing knee reaches **711°/s away from phase seams**, and 1,178°/s including seams. These are demands, not proven actuator speeds. Retime a smooth trajectory against simultaneous torque/speed limits.
- Avoid using exact full extension as recovery margin. Check Jacobian conditioning throughout the transfer, not just endpoint reach. [Modern Robotics, singularities](https://modernrobotics.northwestern.edu/nu-gm-book-resource/5-3-singularities/)
- `comReport()` labels CoM within **one wheel radius** of an axle “over a foot.” A 3″ radius is not a 3″ support patch. Use actual contact geometry and a dynamic stability metric.
- `sim-core.js` filters out robot self-collision. Knee-to-body, leg-to-leg, motor, pulley, and cable interference remain unchecked. Motor envelopes are placeholders.
- The wheel collider is a **6″ sphere**. At the 12.75″ track its total lateral collision envelope is **18.75″**, versus the intended 14″ tire envelope. Its lateral rocking radius also differs from a narrow tire. Planar rolling tests cannot validate lateral fit or one-wheel balance.

Keep 6″ as the current wheel decision. The **±1.75″** slot allowance is correct for the chosen rule that the whole circular silhouette remains between nosing planes. It is a conservative geometry allowance, not a universal support or balance limit.

**9.5″ rise × 9.5″ going is Hux's demanding design fixture, not a nominal residential stair.** Ordinary 2021 IRC stair provisions use a maximum **7¾″ riser** and minimum **10″ tread**. Actual sites and locally adopted provisions vary. Measure the intended stairs; a lower rise can also reduce under-tread clearance, so the square fixture does not bound every collision case. [ICC risers](https://codes.iccsafe.org/s/IRC2021P3/chapter-3-building-planning/IRC2021P3-Pt03-Ch03-SecR311.7.5.1), [ICC treads](https://codes.iccsafe.org/s/IRC2021P3/chapter-3-building-planning/IRC2021P3-Pt03-Ch03-SecR311.7.5.2)

## 2. CoG/CoM: align the whole mass, then calculate joint loads separately

In approximately uniform gravity, **center of gravity and center of mass coincide for this engineering analysis**. Their position relative to actual support contacts matters, along with velocity, acceleration, and angular momentum.

The 2D mass model puts CoM **16.415″ high and 0.245″ behind the axles** with hips directly above the axles. “Hip over wheel” already differs from “CoM over wheel.” The 3D model adds 120 g of tubes, reaching **6.12 kg**; neither has a verified mass inventory or measured inertia tensor.

The earlier claim that hip roll holds approximately zero torque after the sway is **incorrect**. Zero whole-body gravity moment about the contact does not mean zero internal joint torque. With the body upright, the **4 kg body alone**, hanging 5.4″ sideways from the planted hip axis, produces:

`4 × 9.81 × 5.4 × 0.0254 = 5.38 N·m`

That excludes the free leg and other supported components. Calculate the free body supported by the planted hip. The earlier sandbox's ~9 N·m full-lift result is qualitatively consistent with substantial holding load. Do not substitute the 9.53 N·m whole-robot tipping moment for the joint calculation.

`frontView()` shifts the **body center**, while the lateral calculation assigns that position to the **whole CoM**. Wheels and leg mass remain elsewhere. Calculate all transformed link masses.

**One-wheel support is unresolved.** The passing test leaves **15–18% of total weight on the nominally free wheel**; full lift falls. A 1.25″ tire has at most **±0.625″** lateral extent, with a smaller usable footprint on a rounded or cambered tire. Hip motion redistributes mass and angular momentum; it cannot create an arbitrary external restoring moment. Contact forces and momentum must be satisfied together. [MIT, legged-robot contact dynamics](https://underactuated.mit.edu/humanoids.html)

Keep the manual one-leg gate. Test a genuinely clear, unloaded free wheel for the required swing interval plus margin. The current raise/place phases alone take **1.55 s**. A momentary lift or two-contact poise does not satisfy that requirement.

**Use adjustable ballast/pack placement initially.** Moving the 4 kg body lump 1″ forward moves the 6 kg CoM only **⅔″**. It reduces the modeled transfer deficit, but unchanged shove timing overshoots for both +1″ and +2″. Optimize ascent, descent, reverse motion, roll load, and packaging together; the present model does not justify permanently fixing the pack 1–2″ forward.

## 3. Movement: recoverability depends on velocity and grip

The quoted “torque to stop a 10°/20°/30° fall” is an acceleration-scale estimate. It omits initial angular velocity, stopping distance, drivetrain response, and full coupled dynamics. It cannot establish a catch envelope. The **~6°** slot angle is likewise a position-only ratio.

A useful diagnostic is the constant-height point-mass capture point:

`x_capture = x_com + v_com / sqrt(g/h)`

At `h = 0.41694 m`, `sqrt(g/h) = 4.851 /s`. Even with CoM centered, **0.216 m/s** produces a capture-point offset equal to the entire 1.75″ allowance. A wheel must reach that location with finite acceleration, and moving legs change the model. This is a screening calculation, not a safe-speed guarantee. [Pratt et al., Capture Point](https://www.cs.cmu.edu/~cga/legs/Pratt_Goswami_Humanoids2006.pdf)

Tractive moment obeys `|F_t| R ≤ μ N R`. For a 6 kg robot with one wheel carrying the full static weight:

| Assumed μ | Available tractive moment |
| ---: | ---: |
| 0.15 | 0.67 N·m |
| 0.30 | 1.35 N·m |
| 0.50 | 2.24 N·m |
| 0.70 | 3.14 N·m |

**3 N·m of tractive moment needs μ ≈ 0.669** before reserving grip for lateral forces. Half-load gives half these values. Motor torque also accelerates wheel/rotor inertia, so this is not an absolute motor-current cap. Use instantaneous normal load and combined tangential force during lift and landing.

The prescribed 12.75″ lateral sway over 0.85 s has a cubic-profile peak acceleration of **2.69 m/s²**, absent from the 2D friction check. Enforce spatial contact forces and `N ≥ 0`. `contactSplit()` permits small tangential force at near-zero normal load and checks only part of the shove. “Zero cone failures” is not a cycle-wide proof.

## 4. Actuators, springs, and structure

The baseline 2D stair run reports:

| Load | Current result | Assessment |
| --- | ---: | --- |
| Static knee peak | 10.56 N·m | Far above the 4.39 N·m stance example |
| Dynamic knee peak | 19.12 N·m | Above the sandbox's 12 N·m cap |
| Dynamic hip-pitch peak | 6.74 N·m | Above the 3–4 N·m holding guidance |
| Wheel peak estimate | 4.03 N·m | Above proposed 3 N·m peak; two samples away from excluded seams exceed it |

These dynamic numbers are **warnings, not new motor specifications**. The prescribed trajectory has velocity kinks, accelerations are smoothed, seam samples are omitted from peaks, body attitude is constrained, and some forces are assigned after constructing motion. Reflected inertia and realistic actuation are absent. Establish a feasible smooth trajectory before specifying peak/RMS torque. The reported ±6% momentum window belongs to this reduced model, not a measured physical limit.

For each actuator obtain **torque versus speed at loaded bus voltage**, continuous/RMS capability, peak duration, temperature limits, output backlash, reflected inertia, shaft load limits, and output-position accuracy. Test motoring and braking. Stall torque is not a one-second holding guarantee. Reduction increases torque but reflects rotor inertia approximately with the square of ratio.

The **GIM8108-8 name does not establish 4S compatibility**. The manufacturer's catalog contains winding/driver variants and differing voltage ranges; the family page lists nominal torques around 6.6–7.5 N·m and ~396 g with driver. Speed-constant extrapolation does not prove startup or required torque on discharged 4S. Obtain the exact variant drawing and drive limits before adopting its envelope, mass, or ratings. [SteadyWin family page](https://www.steadywin.cn/en/pd.jsp?fromColId=0&id=133), [manufacturer catalog, specification table and variant key](https://www.worldrobotconference.com/profile/robot/download/2025/07/23/20250723171358000848_20250723171358A002.pdf)

The sandbox's active suspension requires **torque-controlled, sufficiently backdrivable joints**. A conventional position servo or open-loop stepper does not reproduce this interface. Real compliance is an alternative, with its own sensing and torque curve. Current-controlled FOC needs appropriate current sensing and rotor feedback; ordinary drone throttle control is not equivalent. [SimpleFOC current control](https://docs.simplefoc.com/foc_current)

The **2.2 N·m spring** offsets the two-leg stance at one angle only. Specify `τ_spring(q)`, preload, travel, stored energy, hysteresis, and unloading behavior. A spring stores impact energy; damping or regeneration must remove it. It may also resist folding the free leg.

The earlier **~90 Hz** tube estimate checks out for a simplified **16×12 mm** cantilever, 190.5 mm long, with assumed 100 GPa modulus and 0.30 kg tip mass. The BOM's **16×14 mm** tube is closer to **70 Hz** under those assumptions. Neither proves assembled resonance. Joint compliance, layup, fittings, and attached inertia matter. At nominal 10 N·m bending, corresponding beam stresses are ~36 and ~60 MPa: demands, **not composite allowables**. Test clamp crushing, pullout, torsion, fitting retention, bearings, and fatigue with actual stock.

“2× two-wheel stance” covers static load transfer only. Illustratively, a **25 mm drop stopped over 5 mm** requires average normal force `mg(1 + 25/5)`, about **353 N at 6 kg**, with potentially higher peaks. Use measured compliance and impact cases for shafts, hubs, bearings, fittings, and gearboxes.

## 5. Controls, sensing, power, and descent

The 500 Hz outer / 2 kHz joint settings are plausible simulation choices, not demonstrated bandwidth. The sandbox reads exact body states and contact impulses without sensor delay or noise. Contact load drives its one-wheel sequence, yet a physical load-estimation system is unspecified.

Recommended implementation contract:

- Local drives close current/torque loops. A deterministic controller owns attitude estimation, joint state, wheel balance, coordinated leg targets, and contact transitions. The Pi supplies bounded high-level requests. “Pose” joints remain dynamically coupled to balance.
- Provide joint/output encoders and calibrated load measurement or estimation. Wheel encoders do not observe slip, carcass twist, or backlash. Validate IMU estimation under acceleration; accelerometers measure specific force, not gravity alone.
- Measure complete sensor-to-torque delay, jitter, bus load, and packet age. At 10 Hz, 10 ms pure delay adds **36° phase lag**. Counting samples during a 57 ms obstacle encounter does not establish adequate response.
- Preserve balance priority over yaw. Include saturation handling, rate limits, watchdogs, and contact-guarded transitions. Gate unloading on measured support and feasible pose; a mode name does not prove contact state.
- Retain the existing classical-control plan. PID versus LQR matters less here than valid plant assumptions, estimation, actuator authority, and contact handling.

**`PARKED` needs a physical support state.** With balance off, the baseline simulator rolls onto its back without the optional skid. Select a rest mechanism or supported sit pose. Distinguish a controlled stop/lower on lost RC while control is healthy from emergency torque removal. Use physical catch/support equipment during early experiments. Shorted motor phases provide speed-dependent braking, not a static parking brake.

**Descent requires its own trajectory and tests.** Reversing the ascent animation does not validate it. One 9.5″ descent releases **14.2 J** at 6 kg, plus changes in kinetic energy. Check landing shock, bus overvoltage, battery charge-current/state-of-charge limits, driver fault behavior, and regulated rails that cannot absorb reverse power. Low mechanical speed does not mean low winding heat while holding a knee. [ODrive power, regeneration, and thermal documentation](https://docs.odriverobotics.com/v/latest/manual/hardware-config.html)

Hattori's first-hand STRIDE V2 account supports motor-at-wheel packaging, serial-leg clearance tradeoffs, and body translation with two leg DOFs. It also describes preliminary open-loop stepping and difficult jump landings. This is useful precedent, not validation of Hux's dimensions or one-wheel controller. [Hattori, STRIDE V2](https://www.alex-hattori.com/blog/wheeled-biped-v2)
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

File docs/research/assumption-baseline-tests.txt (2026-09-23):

> test
> node kin.js && node sim-test.js

kin ok {
  maxStep: '4.28',
  com: 'Over both feet',
  balanceHip: '16.80',
  poke: '2.94',
  kneeBalanceNm: '-4.39',
  behind: '2.71',
  momentum: '0.74',
  needBallistic: '0.77',
  needCatch: '0.69',
  marginCatch: '0.048',
  maxL: '0.78',
  headroom: '0.038',
  leftover: '0.23',
  settleT: '0.61',
  cone: 0,
  crestT: '0.293',
  slotBack: '1.02',
  slotFwd: '1.04',
  cycleS: '5.64',
  peaks: {
    aHip: '6.7',
    aKnee: '6.5',
    bHip: '4.3',
    bKnee: '19.1',
    kneeStatic: '10.6',
    wheel: '4.03',
    roll: '0.0'
  },
  peakWhere: {
    aKnee: 'Roll the rear wheel forward',
    bKnee: 'Throw the mass over the front wheel',
    aHip: 'Throw the mass over the front wheel',
    bHip: 'Throw the mass over the front wheel'
  }
}
sim ok {
  "multibodyTorqueShare": "0.37",
  "freeRoll": {
    "sphere": "0.500",
    "cylinder": "0.602"
  },
  "stance": {
    "kg": "6.12",
    "kneeNm": "1.84",
    "hipHeightIn": "16.8"
  },
  "ride": {
    "pct": "75",
    "hipHeightIn": "14.3",
    "kneeNm": "3.16"
  },
  "drive": {
    "peakLeanDeg": "11.6",
    "peakWheelNm": "2.02",
    "peakKneeNm": "9.1",
    "arcWheelLoadsN": "23/37",
    "crouchKneeNm": "3.9"
  },
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

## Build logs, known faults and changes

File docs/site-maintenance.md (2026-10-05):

# Keeping the HUX plan alive

The website has two named versions: **V1-PROOF** is the current build and **V0-GENESIS** is the original plan model. A third version follows the proof. Its name and scope are not set. Historical `stair-v1` file paths stay intact so that old research references continue to work.

## Update the shared plan

1. Record the decision, the order or the measured result in the applicable source document: [inventory](parts-on-hand.md), [bench sessions](checklists/one-leg-bench-session.md), [acceptance protocol](v1-proof-validation.md) or [decisions](decisions.md).
2. Update `tools/living-drawings/plan-data.json` in the same change. Its version records supply the current actions, purchased parts, milestones, bench sequence and dated updates that the site shows. Update `updatedAt` and include the source references.
3. Keep unknown order quantities and paid costs as `null`. A planned pair of motors does not establish an ordered quantity. Ordered parts are project spend, not free reuse. Record paid orders in V1-PROOF `orders`, with goods, shipping, tax and paid totals. The purchase-card `actualCost` is goods only. Update the public-safe [purchase evidence](purchases.md) and regenerate the budget with `python3 tools/v1-proof/review.py --write`. Never add both the order payments and their goods-only purchase cards.
4. Close a physical milestone only when measured evidence exists for its acceptance criteria. Keep the failed trials and link their session records. Simulation passes do not close physical acceptance.
5. Build and check the site. Then publish the generated output through the deployment process of the current host.

## Bench notes in the browser

The current build page includes a local notebook for work and test observations. Notes persist in that browser when storage is available. They do not change the published plan or synchronize between devices. Export a copy before you clear the browser data. Transfer reviewed measurements into a dated repository session record to make them part of the shared project history.

“Passed” in a local observation describes that recorded trial only. It does not release a whole build stage. Record the setup, the outcome and the evidence. Keep the full [session template](checklists/one-leg-bench-session.md) for physical trials.

The [mechanical testing page](../tools/living-drawings/mechanical-tests.html) adds a movable layout and a dated session journal. Shared steps/history are in `tools/living-drawings/mechanical-tests-data.json`. Actual test events need a dated repository session and linked measurements/evidence.

Device drafts use separate browser storage. Their export/import does not silently replace sessions that conflict, and removed drafts remain available for restoration. Device drafts never close shared gates. Refer to the [recording workflow](mechanical-testing.md).

## Build and preview

Run from `tools/living-drawings`:

```sh
npm run build
npm run test:site
python3 -m http.server 8080 --directory ../../dist/site
```

Open `http://localhost:8080/`. The output is a self-contained static site in `dist/site`. Publish that directory, not the repository checkout or only the original HTML folder. The build renders Markdown into HTML with document navigation and section links. It resolves links against their source files, and it keeps the current interactive drawings and simulations. No browser Markdown renderer or remote document service is necessary.

## Electrical PDFs

The Electrical page includes separate PDF views for EL-01 and EL-05. Each PDF contains one 11 x 17 inch landscape sheet with 0.5 inch margins. The five-sheet atlas uses the same paper size. Print at 100% scale.

After a change to an electrical diagram, regenerate its SVG and PDF in the same commit. Run `node cad/wiring/render.mjs` from the repository root. This command rebuilds all electrical SVGs, registers, PNGs and PDFs from their shared sources. Refer to the [electrical export procedure](../cad/wiring/README.md) for the runtime requirements and visual checks.

The export manifest records hashes of the source files and outputs. The site build rejects missing or stale exports before it changes the output directory. The production publisher uses the same check. Do not change the manifest by hand to bypass a failed check.

## Published assets

Local vendor downloads in `cad/vendor`, optional derived meshes in `tools/living-drawings/models`, and the locally extracted duplicate `cad/prints/v1-proof-r01/hux-v1-proof-r01` stay out of the published bundle. The canonical print-kit folder and ZIP remain published. The archived sandbox supports its current envelope-geometry fallback. Styles and direct script assets receive content-based cache keys so that rebuilt pages load the updated files.

The current project has six primary sections, with the same navigation on drawings, simulations and rendered documents:

| Section | Published route | Contents |
| --- | --- | --- |
| Overview | `/` (also `/v1-proof.html`) | Active scope, assembly rendering, design targets and current status |
| Mechanical | `/mechanical.html` | Assembly, interactive general arrangement and drawing register |
| Electrical | `/electrical.html` | EL-01–04 wiring atlas, enlarged vector viewer, printable PDF and architecture |
| Build & test | `/build.html` | Workbench, milestones, updates and local session notebook |
| Parts & budget | `/parts.html` | Paid orders, shopping list, component register and allowances |
| Documents | `/documents.html` | Discipline-grouped source register and historical archive |

Mechanical includes `/joints.html` for close-up detail studies and links to `/mechanical-tests.html`. Electrical includes `/controls.html`. Build & test links to the current simulation evidence and the 3D sandbox. `/v0-genesis.html` keeps the old plan model. `/docs/…html` remains the readable route for each source guide.

The builder supplies the shared header, the breadcrumbs, the section navigation and the footer. New authored pages use `workshop.css` after their page styles. Edit the navigation in `build_site.py`. Do not add a second header.

`workshop.js` keeps old homepage bookmarks such as `/#build`, `/#model`, `/#connections` and `/#budget`. It forwards them to the dedicated page. The publication step also relocates repository links to these old fragments. Keep the local notebook storage keys intact when you reorganize pages.

Joint studies remain open. The source-checked EL-01–04 wiring atlas replaces the electrical placeholders. Its [verification record](wiring-atlas.md) keeps the unresolved circuits and the physical harness release visible.

Replace placeholders with measured photographs or reviewed drawings only when their evidence exists. Keep the sheet identifiers and the release status. The source Markdown remains editable in the repository. The site links to the rendered pages.

## Writing standard

All active text obeys Simplified Technical English (STE). The rules and the project names are in [writing-standard.md](writing-standard.md). `npm run test:site` runs `python3 tools/ste/check_repo.py`, the STE gate. The site build fails when the gate finds an error. Run the gate on each document before you publish.

## Live publishing and freshness

The signed GitHub push hook for `main` uses the host configuration in [nova-centauri/vps-1](https://github.com/nova-centauri/vps-1/blob/main/docs/hux.md). The deploy script builds a separate release with the Python publisher of this repository. It validates the links of the release, then atomically switches the published directory. A failed build keeps the prior release. Failed post-publish route/revision checks restore the prior release. Generated output is not committed to this repository.

Check [deployment.json](https://hux.xer0.io/deployment.json): its `revision` must equal the intended Hux Git commit. Then make sure that the live [budget](https://hux.xer0.io/docs/bom.html), [paid orders](https://hux.xer0.io/docs/purchases.html), [motor connections](https://hux.xer0.io/docs/electronics.html) and [control architecture](https://hux.xer0.io/docs/software.html) are correct. Also make sure that the orders and totals on the homepage are correct. [build-report.json](https://hux.xer0.io/build-report.json) must report no errors. A successful push or a homepage HTTP 200 alone does not establish that the new guides and data are current.

Use `npm test` for the current model and simulation regression checks. Run `npm run test:legacy` when you change the historical engineering or simulator behavior.

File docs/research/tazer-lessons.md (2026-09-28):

> **PARKED STAIR-V1 — 2026-09-28.** This is historical research, not an active requirement, BOM or build gate. [V1-PROOF](../v1-proof.md) governs current work.

# Tazer — learn from the mistakes

> **2026-09-28:** historical study. Current head/leg dimensions, procurement and support gates are in [the engineering review](../head-and-leg-review.md). No components have been purchased; older order/selection claims are superseded.

Steve 2026-09-21: watch [My Robot almost got me Kicked out of Uni](https://www.youtube.com/watch?v=gqnW9qBCHnM) (Tazer) and **learn a lot from this guy's mistakes**. Inspiration + anti-patterns. **Not a Hux stack, BOM, or CAD source.** No spend. FC stays **TBD**.

This sits next to [inspiration.md](inspiration.md). It does not replace [XRobots](xrobots.md), Hattori, Serra, or [study-plan.md](study-plan.md) Phases A–D.

Index: [`inspiration.md`](inspiration.md). Actuator trade: [`actuators-legs.md`](actuators-legs.md). Shop: [`../capabilities.md`](../capabilities.md). Power: [`../electronics.md`](../electronics.md). Decisions: [`../decisions.md`](../decisions.md).

## What he built (relevant to Hux)

Maker-scale **wheeled biped**, about **0.7 m (~2 ft)** tall — same height class as Hux's **~24"** full-extension envelope (R35).

| Piece (theirs) | Hux take |
| --- | --- |
| Octagonal **carbon-fiber tube** legs | Confirms Hux **carbon-tube spars** (R34). Steal the *material*, not their section or CAD. Tube OD / wall still TBD. No SKU. |
| **6× GIM8108** QDD-class actuators (2 joints + 1 wheel per leg) | **GIM8108-8** is already a Hux *candidate* for knee / swing — **not ordered, not locked**. His wheel motors being the same family is a data point, not a Hux wheel SKU. Knee / hip swing stay **servo vs stepper+belt TBD** (R12). Wheels stay **in-wheel FOC** (R6 / R30). |
| **CAN** between actuators | Pattern, not a bus lock. Hux I/O is TBD with the class. |
| Teensy 4.1 + BNO055 IMU | **Not a Hux FC.** Hux FC stays **TBD** (on-hand Wing / drone pile). Steal “IMU on the balance brain,” not the MCU. |
| T8S RC | Hux RX is **TBS Nano**. Steal stick *semantics*, not the radio. |
| Dual **6S in series (~48 V)** for actuators, buck for logic | Hux prefers **4S + regulated step-down** (R11). His bus is heavier than we want. The lesson is **serious power distribution for FOC stalls**, not “copy 48 V.” |
| Silicone / real rubber tires (not TPU) | Real rubber stands. The **5" Zantle is a bench donor, not the foot.** Settled contact is **6" OD**, torsionally stiff ([`leg-geometry.md`](leg-geometry.md)). Do not print TPU treads. |
| Backdrivable **low-reduction** actuators for impacts | Matches hip-roll **dynamic / QDD / fast servo** lean (R16 / R27). Do not put a stiff stepper on roll. |

**Do not** vendor his files, copy his 48 V stack, lock GIM8108, or buy a Teensy “because Tazer.”

## Mistakes / lessons to steal

Focus of this note. Rewrite in Hux terms.

1. **Wrong motors the first time.** Bad advice → wrong actuator type → **~$600 wasted**. Verify the *class* (QDD / backdrivable vs stiff position vs hobby servo) **before** anyone spends. Hux already forbids spend until Steve asks and forbids SKU locks. Treat “a friend said buy X” as a research pointer, not a cart.
2. **TPU tires = zero traction.** Use **real rubber / silicone**. Hux: not a printed TPU tread. The 5" walker donors are bench rubber only. The settled contact is a torsionally stiff **6"** tire ([`leg-geometry.md`](leg-geometry.md)).
3. **Power path underspec’d.** His actuators were about **7 A nominal / 22 A stall each**. Six axes can demand huge current. A PCB used as the power bus nearly blew. **Plan dedicated power distribution**, not skinny traces. Hux 4S is lighter than his 48 V stack and still needs a real bus for two FOC wheels + pose + roll stalls.
4. **Don’t feed all motor power through a delicate logic PCB.** Separate power plane / harness from the FC / Pi / IMU board. The FC is TBD — still do not route wheel-ESC current across it.
5. **CAN termination gotchas.** Actuators may already have terminators. He burned **14 hours** on this. If Hux later uses CAN (roll / QDD path), treat termination as a first-class bring-up item, not a footnote.
6. **Broken / weak actuator in the set.** ~40% torque mismatch, false power readings, encoder fail, random sleep. **Keep spares** (later, when Steve buys). Measure torque on the bench. Do not trust one unit. Do not buy a set yet.
7. **LQR with a bad model wasted time.** A **PID cascade** is what actually got balance working. Start simple. This is Hux **R18** (reuse existing control — XRobots IMU → PID → wheel torque) in someone else's blood. Do not invent an LQR / model-based Hux stack for V1.
8. **Absolute encoder / homing.** Swapping motors lost absolute pose. Plan **startup / home** or **absolute encoders from day one** — especially if pose joints are steppers (open-loop lies after a missed step) or QDD modules with multi-turn assumptions.
9. **Mechanical assembly orientation error.** A link on the wrong side made the robot too wide. Hux V1 width is **~14"** (R15). Use a fixture / checklist for left vs right (already a 2D + serviceability habit).
10. **Carbon dust safety.** Respirator + **wet cut** when cutting carbon tube. Shop note: [`../capabilities.md`](../capabilities.md). Do not dry-bandsaw a cloud of carbon into the mill.
11. **Single-point reliability before demos.** The robot broke the day before graduation. Design for **serviceability** (R22 already) and bring-up margin. Do not schedule a demo on the first machine that balances.
12. **Torque / speed limits in software matter.** A runaway joint is an injury risk. When firmware exists: clamp pose rates and wheel torque. Not a reason to write firmware now.

## Hux takeaways

1. **GIM8108-class is a live candidate** for knee / swing (and a data point for wheels). Still **not ordered**. Knee / hip swing remain **TBD**. Hip roll stays **dynamic in V1**.
2. **Carbon tubes are the confirmed path** (R34). His ~2 ft machine is a scale rhyme with Hux ~24".
3. **4S may be lighter than his ~48 V stack** — keep 4S + step-down (R11). Still need **serious PDB / harness** for FOC stalls. Do not use the FC or a logic PCB as the power bus.
4. **Prefer simple balance first** (PID cascade / existing patterns). LQR-with-a-wrong-model is how you lose a month. R18.
5. **Rubber, not TPU.** Zantle 5" is ordered as a bench donor. The foot is real rubber at **6"** ([`leg-geometry.md`](leg-geometry.md)). Not a buy.
6. **Log this as inspiration + anti-patterns**, not as a shopping list.

## Cite

- **Tazer** — [My Robot almost got me Kicked out of Uni](https://www.youtube.com/watch?v=gqnW9qBCHnM)

What we took: anti-patterns (wrong first motors, TPU tires, skinny power, logic-PCB bus, CAN termination, bad unit in a set, LQR-too-early, no homing, left/right assembly, carbon dust, demo-eve breakage, missing software limits). What we did **not** copy: 48 V, Teensy, T8S, a GIM8108 buy, geometry, firmware.

## Do not

- Spend, or treat his 6× GIM8108 / 48 V / Teensy bill as a Hux spec
- Lock GIM8108, CAN, or a 48 V pack
- Print TPU treads as the traction plan
- Route motor current through the FC or a proto logic board
- Start V1 on LQR / a novel model-based stack
- Skip carbon-dust PPE
- Vendor his CAD / code

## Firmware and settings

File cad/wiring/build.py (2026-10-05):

#!/usr/bin/env python3
"""Rebuild the source-checked V1-PROOF wiring sheets (standard library only).

Functional blocks are not invented connector layouts. Only Pico, SparkFun IMU
and Pololu carrier pad arrangements are presented as component-side views.
"""
from pathlib import Path
from html import escape
import json
import xml.etree.ElementTree as ET

HERE = Path(__file__).resolve().parent
W, H = 1680, 1120
C = dict(ink='#20343e', muted='#647780', line='#ced8d7', paper='#f7f5ee',
         red='#db5a4a', orange='#c77822', purple='#8260a9', cyan='#218ca0',
         blue='#437fb4', yellow='#bd9221', ground='#52676d', green='#387b65', white='#fffef9')
PIN = {0:1,1:2,2:4,3:5,4:6,5:7,6:9,7:10,8:11,9:12,10:14,11:15,
       12:16,13:17,14:19,15:20,16:21,17:22,18:24,19:25,20:26,21:27,
       22:29,26:31,27:32,28:34}
FUNCTION = {0:'Manual TX (optional)',1:'Manual RX (optional)',2:'Left encoder A',3:'Left encoder B',
            4:'Right encoder A',5:'Right encoder B',6:'Left EN / PWM',7:'Left PH / direction',
            8:'Right EN / PWM',9:'Right PH / direction',10:'Wheel enable request',11:'Left FAULT',
            12:'SPI1 MISO',13:'SPI1 chip select',14:'SPI1 clock',15:'SPI1 MOSI',16:'IMU INT1 / DRDY',
            17:'Servo bus direction',18:'Right FAULT',19:'Deliberate arm input',20:'UART1 servo TX',
            21:'UART1 servo RX',22:'Watchdog heartbeat',26:'Left CS via conditioning',
            27:'Right CS via conditioning',28:'Pack voltage via divider'}

class Sheet:
    def __init__(self, number, name, subtitle, width=W, height=H, tabloid=False):
        self.number, self.name = number, name
        self.width,self.height=width,height
        self.tabloid=tabloid
        self.output_height=2000 if tabloid else height
        page_height=self.output_height
        self.p = [f'<svg xmlns="http://www.w3.org/2000/svg" width="{width}" height="{page_height}" viewBox="0 0 {width} {page_height}" role="img" aria-labelledby="title desc">',
                  f'<title id="title">Hux V1-PROOF {escape(name)}</title><desc id="desc">{escape(subtitle)} Source-checked planning drawing; proposed harnesses and unresolved interfaces require physical verification.</desc>',
                  '<defs><pattern id="grid" width="24" height="24" patternUnits="userSpaceOnUse"><circle cx="12" cy="12" r=".7" fill="#c9d5d1"/></pattern></defs>']
        self.rect(0,0,width,page_height,'#ffffff' if tabloid else C['paper'])
        self.p.append(f'<rect x="32" y="32" width="{width-64}" height="{page_height-64}" fill="{ "none" if tabloid else "url(#grid)"}" stroke="{C["line"]}"/>')
        self.text(64,72,'HUX  /  V1-PROOF  /  ELECTRICAL',20 if tabloid else 13,C['green'],700,spacing=2)
        self.text(64,119,name,44 if tabloid else 38,C['ink'],700)
        self.text(64,150,subtitle,20 if tabloid else 16,C['muted'])
        self.rect(width-(610 if tabloid else 330),58,546 if tabloid else 266,65 if tabloid else 58,'#ece7d7',8)
        self.text(width-(337 if tabloid else 197),86 if tabloid else 82,'SOURCE-CHECKED PLAN',20 if tabloid else 12,C['ink'],700,'middle',1)
        self.text(width-(337 if tabloid else 197),112 if tabloid else 103,'HARNESS / BENCH RELEASE OPEN',18 if tabloid else 10,C['muted'],500,'middle',1)
        self.line([(64,174),(width-64,174)],C['line'],1)
        self.line([(64,page_height-90),(width-64,page_height-90)],C['line'],1)
        self.text(64,page_height-60,'Rev B  |  Source: 04 OCT 2026  |  Print layout: 05 OCT 2026' if tabloid else 'Rev B  |  04 OCT 2026  |  Vendor pinouts + proposed Hux circuits',20 if tabloid else 12,C['muted'])
        self.text(64,page_height-34 if tabloid else page_height-38,'17 x 11 in / landscape / 0.5 in margins / print at 100%. Sources and open checks: docs/wiring-atlas.md.' if tabloid else 'See docs/wiring-atlas.md and the wire register for sources and open circuit decisions.',18 if tabloid else 11,C['muted'])
        self.text(width-66,page_height-56,number,30 if tabloid else 25,C['green'],700,'end')

    def layout_y(self,y):
        # Reflow coordinates, not glyphs or circular symbols. The same vector
        # layout supplies the screen drawing, PDF, and endpoint register.
        if not self.tabloid:return y
        return round(174+(y-174)*(self.output_height-264)/(self.height-264),3)

    def layout_point(self,point):
        return [point[0],self.layout_y(point[1])]

    def layout_body(self,markup):
        body=ET.fromstring('<g id="circuit">'+markup+'</g>')
        if self.tabloid:
            for element in body.iter():
                if 'y' in element.attrib:
                    y=float(element.attrib['y'])
                    element.set('y',str(self.layout_y(y)))
                    if 'height' in element.attrib:
                        element.set('height',str(round(self.layout_y(y+float(element.attrib['height']))-self.layout_y(y),3)))
                if 'cy' in element.attrib:element.set('cy',str(self.layout_y(float(element.attrib['cy']))))
                if 'points' in element.attrib:
                    element.set('points',' '.join(f'{x},{self.layout_y(float(y))}' for x,y in (p.split(',') for p in element.attrib['points'].split())))
                if element.tag=='text':element.set('font-size',str(max(18,float(element.attrib['font-size']))))
        return ET.tostring(body,encoding='unicode')
    def rect(self,x,y,w,h,fill=None,r=0,stroke=None,dash=False):
        self.p.append(f'<rect x="{x}" y="{y}" width="{w}" height="{h}" rx="{r}" fill="{fill or C["white"]}" stroke="{stroke or C["line"]}" stroke-width="1.4"'+(' stroke-dasharray="7 5"' if dash else '')+'/>')
    def text(self,x,y,t,size=16,color=None,weight=400,anchor='start',spacing=0):
        self.p.append(f'<text x="{x}" y="{y}" font-family="Arial,Helvetica,sans-serif" font-size="{size}" font-weight="{weight}" text-anchor="{anchor}" letter-spacing="{spacing}" fill="{color or C["ink"]}">{escape(str(t))}</text>')
    def line(self,points,color=None,width=3,dash=False):
        self.p.append('<polyline points="'+' '.join(f'{x},{y}' for x,y in points)+f'" fill="none" stroke="{color or C["cyan"]}" stroke-width="{width}" stroke-linejoin="round" stroke-linecap="round"'+(' stroke-dasharray="7 5"' if dash else '')+'/>')
    def dot(self,x,y,color=None,r=4):
        self.p.append(f'<circle cx="{x}" cy="{y}" r="{r}" fill="{color or C["cyan"]}"/>')
    def port(self,x,y,color):
        self.p.append(f'<circle cx="{x}" cy="{y}" r="5" fill="{C["white"]}" stroke="{color}" stroke-width="2.5"/>')
    def label(self,x,y,t,color=None,size=13):
        self.rect(x-6,y-size-2,len(t)*size*.55+12,size+9,C['paper'],3,C['paper'])
        self.text(x,y,t,size,color or C['muted'],600)
    def card(self,x,y,w,h,kicker,title,lines=(),color=None,pending=False):
        color=color or C['green']
        self.rect(x,y,w,h,C['white'],10,C['line'],pending)
        self.rect(x,y,6,h,color,3,color)
        self.text(x+22,y+26,kicker,11,color,700,spacing=1)
        self.text(x+22,y+56,title,22,C['ink'],700)
        for i,t in enumerate(lines): self.text(x+22,y+82+i*23,t,14,C['muted'])
    def ground(self,x,y):
        self.line([(x,y),(x,y+14)],C['ground'],2.5)
        for yy,ww in [(14,20),(20,13),(26,5)]: self.line([(x-ww/2,y+yy),(x+ww/2,y+yy)],C['ground'],2.5)
    def note(self,x,y,w,kicker,lines,color=None):
        self.card(x,y,w,58+len(lines)*23,kicker, '',[],color or C['orange'])
        for i,t in enumerate(lines): self.text(x+22,y+55+i*23,t,14,C['muted'])
    def save(self,stem):
        path=HERE/f'{stem}.svg'
        path.write_text('\n'.join(self.p)+ '\n</svg>\n')
        return path

def overview():
    s=Sheet('EL-01','Wiring overview','A four-actuator architecture with separate power, sensing and hardware enable paths.')
    s.card(64,207,410,113,'POWER / PROPOSED PACK','3S battery', ['Up to 12.6 V charged; pack / charger TBD'],C['red'],True)
    s.card(64,357,410,94,'PROTECTION / VALUES TBD','Main fuse + distribution',[],C['red'],True)
    s.card(64,508,410,113,'PHYSICAL CUT / CIRCUIT TBD','Actuator power cut',['Opens wheel + servo positive supply'],C['red'],True)
    s.card(64,693,410,126,'LOGIC BRANCH / CIRCUIT TBD','5 V regulator + power ORing',['Feeds Pico VSYS and both encoders','USB / external-power isolation required'],C['orange'],True)
    s.card(64,878,410,123,'SERVO BRANCH / CIRCUIT TBD','Regulated + protected 9 V',['About 6 A short-peak sizing target','Return-energy handling to be qualified'],C['purple'],True)
    s.card(642,207,420,120,'RECEIVED / UNTESTED','SparkFun LSM6DSO',['3.3 V • main SPI • INT1 data-ready','Open address jumper for SPI  [EL-02]'])
    s.card(642,407,420,220,'RECEIVED / UNTESTED','Raspberry Pi Pico 2',[
        '3.3 V GPIO; proposed allocation [EL-02]','SPI1 sensor / encoder feedback',
        'PWM + direction / current + fault inputs','USB commands + logs; 250 ms deadman',
        'Balance firmware remains unimplemented'])
    s.card(642,702,420,103,'HARDWARE ENABLE / CIRCUIT TBD','Watchdog + kill gate',['GP10 request AND healthy watchdog / cut'],C['red'],True)
    s.card(642,878,420,123,'SERVO INTERFACE / PART TBD','Half-duplex TTL interface',['UART1 TX / RX + GP17 direction','3.3 V MCU side; verify bus logic levels'],C['cyan'],True)
    for y,side,pins in [(207,'Left','GP6 / 7 • FAULT GP11 • CS GP26'),(475,'Right','GP8 / 9 • FAULT GP18 • CS GP27')]:
        s.card(1210,y,406,194,'WHEEL CHANNEL / EL-03',side+' DRV8874 → 4752',[
            pins,'Motor red → OUT1; black → OUT2',
            '5 V encoder → level shift → Pico',
            'Left GP2 / 3; right GP4 / 5'],C['blue'])
    s.card(1210,878,406,123,'LEG ACTUATORS / EL-04','2 × ST3215, 12 V variant',[
        'Qualify holding performance at 9 V','Unique bus IDs; arrival unreported'],C['purple'])
    # Rails. Each junction dot represents an actual branch; line crossings do not.
    s.line([(270,320),(270,357)],C['red'],5)
    s.line([(270,451),(270,508)],C['red'],5)
    s.line([(474,402),(517,402),(517,748),(474,748)],C['orange'],4)
    s.dot(474,402,C['red'])
    s.line([(474,563),(563,563),(563,372),(1180,372),(1180,294),(1210,294)],C['red'],5)
    s.line([(1180,372),(1180,565),(1210,565)],C['red'],5);s.dot(1180,372,C['red'])
    s.line([(563,563),(563,937),(474,937)],C['red'],5);s.dot(563,563,C['red'])
    s.label(599,365,'SWITCHED ACTUATOR BUS',C['red'])
    s.line([(474,787),(605,787),(605,563),(642,563)],C['orange'],4)
    s.label(526,670,'VSYS p39',C['orange'],12)
    s.line([(852,327),(852,407)],C['cyan'],4);s.label(866,365,'SPI + INT1',C['cyan'])
    s.line([(1062,472),(1104,472),(1104,254),(1210,254)],C['cyan'],3)
    s.line([(1104,472),(1104,522),(1210,522)],C['cyan'],3);s.dot(1104,472)
    s.label(1077,433,'I/O',C['cyan'])
    s.line([(830,627),(830,702)],C['red'],3);s.label(847,668,'GP10 / GP22',C['red'])
    s.line([(1062,754),(1144,754),(1144,333),(1210,333)],C['red'],3,True)
    s.line([(1144,603),(1210,603)],C['red'],3,True);s.dot(1144,603,C['red'])
    s.label(1108,686,'SLEEP',C['red'])
    # UART originates at the Pico. Offset path avoids the enable gate.
    s.line([(1062,610),(1090,610),(1090,749)],C['cyan'],3)
    s.line([(1090,759),(1090,851),(1027,851),(1027,878)],C['cyan'],3)
    s.label(863,848,'UART1 / GP17',C['cyan'])
    s.line([(1062,928),(1210,928)],C['cyan'],3);s.label(1078,916,'TTL DATA',C['cyan'],12)
    s.line([(474,975),(593,975),(593,1010),(1178,1010),(1178,972),(1210,972)],C['purple'],4)
    s.label(783,1001,'PROTECTED 9 V SERVO POWER',C['purple'])
    s.note(1210,714,406,'READING THE SHEET',[
        'Links marked I/O bundle multiple wires.',
        'All GND returns share a common reference.',
        'Dots join wires; crossings do not.',
        'Dashed blocks need a selected circuit.'])
    return s.save('v1-proof-el-01-overview')

def pico_imu():
    s=Sheet('EL-02','Pico 2 + IMU connections','Component-side views, USB at the top of the Pico. Physical pins and GPIO numbers are distinct.')
    # Actual 40-pin Pico top view. Left p1->20, right p40->21.
    s.rect(220,246,290,704,'#2e6756',13,'#245445')
    s.rect(328,228,74,47,'#bac8c7',5,'#7f9391')
    s.text(365,294,'USB',13,'#f6f9ec',700,'middle')
    s.rect(303,548,123,92,'#26343d',6,'#26343d')
    s.text(365,589,'RP2350',16,'#f6f9ec',700,'middle')
    s.text(365,617,'PICO 2',12,'#c6d5d0',600,'middle')
    s.text(365,912,'TOP VIEW',12,'#d7e4d8',600,'middle',1)
    left=[0,1,'GND',2,3,4,5,'GND',6,7,8,9,'GND',10,11,12,13,'GND',14,15]
    right=['VBUS','VSYS','GND','3V3_EN','3V3(OUT)','ADC_VREF',28,'AGND',27,26,'RUN',22,'GND',21,20,19,18,'GND',17,16]
    for bank,items in [('L',left),('R',right)]:
        for i,item in enumerate(items):
            y=264+i*35;num=i+1 if bank=='L' else 40-i
            gp=isinstance(item,int);name=f'GP{item}' if gp else item
            col=C['cyan'] if gp else C['ground']
            if item in ['3V3(OUT)']:col=C['purple']
            if item=='VSYS':col=C['orange']
            x=237.5 if bank=='L' else 492.5
            s.rect(x-6,y-7,12,14,'#dbc577',2,'#e8d895')
            s.dot(x,y,C['ink'],2)
            s.text(257 if bank=='L' else 473,y+4,num,11,'#f5f7e8',600,'start' if bank=='L' else 'end')
            s.text(207 if bank=='L' else 531,y+5,name,14,col,700,'end' if bank=='L' else 'start')
    s.text(64,217,'PHYSICAL PIN MAP',12,C['green'],700,spacing=1)
    s.text(64,990,'p1 is upper left; p40 is upper right.',14,C['muted'])
    s.text(642,217,'SEVEN-WIRE SENSOR HARNESS',12,C['green'],700,spacing=1)
    # Main IMU pads in a correct 90-degree clockwise top view.
    s.rect(1240,300,360,360,'#bb343e',8,'#9d2932')
    s.rect(1374,282,92,38,'#e5dfd4',4,'#b4aca1');s.rect(1374,641,92,38,'#e5dfd4',4,'#b4aca1')
    s.text(1420,308,'QWIIC',10,'#3a4141',700,'middle');s.text(1420,666,'QWIIC',10,'#3a4141',700,'middle')
    s.rect(1373,443,94,82,'#26343d',5,'#26343d')
    s.text(1420,473,'LSM6',13,'#f5f5ed',700,'middle');s.text(1420,495,'DSO',13,'#f5f5ed',700,'middle')
    s.text(1420,618,'SEN-18020',14,'#fff6e9',700,'middle')
    main=['GND','3V3','SDA / SDI','SCL','SDO','CS']
    aux=['INT2','INT1','OCS','SCX','SDIX','SDOX']
    rows=[('GND p18','GND',C['ground']),('3V3(OUT) p36','3V3',C['purple']),
          ('GP15 p20 · MOSI','SDA / SDI',C['cyan']),('GP14 p19 · SCK','SCL',C['blue']),
          ('GP12 p16 · MISO','SDO',C['green']),('GP13 p17 · CS','CS',C['orange'])]
    for i,(pico,imu,col) in enumerate(rows):
        y=390+i*36
        s.rect(650,y-16,402,31,C['white'],5)
        s.text(670,y+5,pico,17,C['ink'],600)
        s.line([(1052,y),(1258,y)],col,4);s.port(1052,y,col)
        s.rect(1252,y-6,12,12,'#ebc976',2,'#ebc976');s.dot(1258,y,C['ink'],2)
        s.text(1270,y+5,main[i],13,'#fff6e9',600)
        s.rect(1576,y-6,12,12,'#ebc976',2,'#ebc976');s.dot(1582,y,C['ink'],2)
        s.text(1563,y+5,aux[i],12,'#fff6e9',600,'end')
    s.rect(650,709,402,43,C['white'],5);s.text(670,737,'GP16 p21 · INT1 / DRDY',17,C['ink'],600)
    s.line([(1052,731),(1620,731),(1620,426),(1582,426)],C['yellow'],4)
    s.port(1052,731,C['yellow']);s.port(1582,426,C['yellow'])
    s.text(1240,259,'SPARKFUN / COMPONENT SIDE',12,C['green'],700,spacing=1)
    s.text(1240,282,'Rotated 90° clockwise from vendor view',13,C['muted'])
    s.note(642,805,974,'SPI JUMPER SETUP / CHECK RECEIVED BOARD',[
        'Open the 0x6B / 0x6A address jumper so SDO can drive MISO.',
        'Recommended: open both I2C pull-up traces. Keep SCX / SDIX ground jumpers intact.',
        'Qwiic sockets carry I2C and are unused here. Wire the main SPI pads, not SCX / SDIX.',
        'Power and signal logic are 3.3 V. Inspect board revision and check sensor identity before use.'])
    return s.save('v1-proof-el-02-pico-imu')

def wheel():
    s=Sheet('EL-03','Wheel motor + encoder harness','One channel shown; repeat for the other wheel using the assignment table. Colors match the motor leads.')
    s.card(64,212,434,114,'PICO / PROPOSED OUTPUTS','3.3 V command signals',['Use the left / right GPIO table below.'],C['cyan'])
    # Precise physical top view of the 4035 carrier.
    s.rect(663,246,292,337,'#254d78',8,'#254d78')
    s.text(809,222,'POLOLU 4035 / TOP VIEW',12,C['blue'],700,'middle',1)
    s.rect(778,354,65,102,'#253442',3,'#253442')
    s.text(811,393,'DRV',11,'#e5edf2',700,'middle');s.text(811,413,'8874',11,'#e5edf2',700,'middle')
    left=['VM','GND','EN / IN1','PH / IN2','PMODE','SLEEP','VREF']
    right=['VIN','GND','OUT1','OUT2','IMODE','FAULT','CS']
    for i in range(7):
        y=279+i*44
        for x,label,anchor,tx in [(678,left[i],'start',693),(940,right[i],'end',925)]:
            s.rect(x-5,y-6,10,12,'#dfce85',2,'#dfce85')
            s.text(tx,y+4,label,12,'#f0f4ee',600,anchor)
    for y,label in [(367,'EN / PWM'),(411,'PH / direction'),(499,'Gated SLEEP')]:
        s.text(86,y+5,label,17,C['cyan'],600)
        s.line([(296,y),(678,y)],C['red'] if 'SLEEP' in label else C['cyan'],3)
        s.port(296,y,C['red'] if 'SLEEP' in label else C['cyan'])
    s.text(521,263,'VM: leave unused',12,C['muted'])
    s.line([(678,279),(570,279)],C['muted'],2)
    for x,y in [(678,323),(940,323)]:s.line([(x,y),(634 if x==678 else 984,y)],C['ground'],3);s.ground(634 if x==678 else 984,y)
    s.line([(678,455),(598,455)],C['ground'],3);s.ground(598,455)
    s.line([(940,455),(1024,455)],C['ground'],3);s.ground(1024,455)
    s.text(503,608,'PMODE + IMODE directly to GND',14,C['ground'],700)
    s.line([(940,279),(1123,279),(1123,221)],C['red'],5)
    s.label(1137,247,'Switched bus +',C['red'])
    s.card(1232,320,384,163,'POLOLU 4752 / MOTOR LEADS','12 V, 30:1 gearmotor',[
        'RED lead  →  OUT1','BLACK lead  →  OUT2','Both motor leads are switched.'],C['blue'])
    s.line([(940,367),(1232,367)],C['red'],5)
    s.line([(940,411),(1232,411)],C['ink'],5)
    s.label(1038,355,'RED',C['red']);s.label(1038,399,'BLACK ≠ GND',C['ink'])
    s.line([(940,499),(1086,499),(1086,610),(1232,610)],C['yellow'],3)
    s.card(1232,533,384,135,'FAULT / CURRENT INPUTS','Return to Pico via protection',[
        'FAULT → GP11 / GP18; 3.3 V pull-ups','CS → GP26 / GP27 via protection TBD','Latch faults; deliberate rearm required.'],C['yellow'],True)
    s.line([(940,543),(1062,543),(1062,644),(1232,644)],C['blue'],3)
    s.line([(678,543),(542,543),(542,638)],C['orange'],3)
    s.rect(498,638,463,38,C['white'],5,C['orange'],True)
    s.text(518,662,'VREF network TBD: set + measure 2.5 A peak',13,C['orange'],600)
    # Separate encoder sub-harness, functional wire order; not a connector view.
    s.card(1232,715,384,228,'4752 / ENCODER LEADS','Four-wire feedback harness',[
        'GREEN  →  common GND','BLUE  →  regulated 5 V',
        'YELLOW  →  channel A','WHITE  →  channel B',
        'Connector orientation: verify by color.'],C['green'])
    s.card(649,731,414,196,'REQUIRED INTERFACE / PART TBD','5 V → 3.3 V level conversion',[
        'Four input channels for both wheels','Use a translator suitable for push-pull',
        'quadrature outputs; check power-off state.','No direct 5 V signals into Pico GPIO.'],C['green'],True)
    s.line([(1090,797),(1232,797)],C['green'],3);s.port(1090,797,C['green'])
    s.label(1092,785,'GND / GREEN',C['green'],12)
    s.line([(1090,820),(1232,820)],C['blue'],3);s.port(1090,820,C['blue'])
    s.label(1092,811,'5 V / BLUE',C['blue'],12)
    for y,label,col in [(851,'A / YELLOW',C['yellow']),(891,'B / WHITE',C['ground'])]:
        s.line([(1232,y),(1063,y)],col,5 if 'WHITE' in label else 3)
        if 'WHITE' in label:s.line([(1232,y),(1063,y)],C['white'],2.7)
        s.label(1092,y-10,label,col,12)
    s.line([(649,799),(498,799)],C['cyan'],3);s.line([(649,834),(498,834)],C['cyan'],3)
    s.card(64,684,434,283,'PICO / LEFT AND RIGHT CHANNELS','Proposed pin assignments',[],C['cyan'])
    s.text(86,779,'Function',14,C['muted'],600);s.text(256,779,'Left',14,C['muted'],600);s.text(369,779,'Right',14,C['muted'],600)
    rows=[('Encoder A',2,4),('Encoder B',3,5),('EN / PH',6,8),('FAULT',11,18),('CS / ADC',26,27)]
    for i,(name,l,r) in enumerate(rows):
        y=810+i*29
        s.text(86,y,name,14)
        lv=f'{l}/{l+1}' if name=='EN / PH' else str(l)
        rv=f'{r}/{r+1}' if name=='EN / PH' else str(r)
        s.text(256,y,'GP'+lv,14,C['cyan'],600);s.text(369,y,'GP'+rv,14,C['cyan'],600)
    s.text(649,979,'EN low = brake. SLEEP low = outputs off / coast.',15,C['red'],700)
    s.text(649,1002,'2.5 A peak / 1.2 A RMS are Hux qualification targets, not tested settings.',13,C['muted'])
    return s.save('v1-proof-el-03-wheel-harness')
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

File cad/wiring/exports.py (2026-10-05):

#!/usr/bin/env python3
"""Record and check the sources and bytes of the electrical print exports."""

import argparse
import hashlib
import json
from pathlib import Path
import sys

STEMS = (
    'v1-proof-el-01-overview', 'v1-proof-el-02-pico-imu',
    'v1-proof-el-03-wheel-harness', 'v1-proof-el-04-power-servo',
    'v1-proof-el-05-both-wheels',
)
PRINT_PDFS = (
    'v1-proof-el-01-overview-11x17.pdf',
    'v1-proof-el-05-both-wheels-11x17.pdf',
    'v1-proof-wiring-atlas.pdf',
)
INPUTS = ('build.py', 'complete.py', 'render.mjs', 'exports.py',
          *(stem + '.svg' for stem in STEMS))
OUTPUTS = (*PRINT_PDFS, *(stem + '.png' for stem in STEMS))
MANIFEST = 'v1-proof-export-manifest.json'
LAYOUT = {'paper_inches': [17, 11], 'margin_inches': 0.5}


def digest(path):
    return hashlib.sha256(path.read_bytes()).hexdigest()


def write_manifest(directory):
    data = {'schema': 1, 'layout': LAYOUT,
            'sources': {name: digest(directory / name) for name in INPUTS},
            'outputs': {name: digest(directory / name) for name in OUTPUTS}}
    (directory / MANIFEST).write_text(json.dumps(data, indent=2) + '\n')


def check_exports(directory):
    try:
        data = json.loads((directory / MANIFEST).read_text())
    except (OSError, ValueError):
        return ['The electrical export manifest is missing or invalid. Run node cad/wiring/render.mjs.']
    if data.get('schema') != 1 or data.get('layout') != LAYOUT:
        return ['The electrical print layout is stale. Run node cad/wiring/render.mjs.']
    errors = []
    for group, names in [('sources', INPUTS), ('outputs', OUTPUTS)]:
        hashes = data.get(group)
        if not isinstance(hashes, dict):
            errors.append(f'The electrical export manifest needs {group}. Run node cad/wiring/render.mjs.')
            continue
        for name in names:
            path = directory / name
            if not path.is_file() or digest(path) != hashes.get(name):
                errors.append(f'The electrical export is stale: {name}. Run node cad/wiring/render.mjs.')
    return errors


def main():
    parser = argparse.ArgumentParser(description=__doc__)
    parser.add_argument('--write', action='store_true')
    args = parser.parse_args()
    directory = Path(__file__).resolve().parent
    if args.write:
        write_manifest(directory)
    errors = check_exports(directory)
    for error in errors:
        print(error, file=sys.stderr)
    if not errors:
        print('Electrical PDFs and PNGs match the drawing sources.')
    return bool(errors)


if __name__ == '__main__':
    sys.exit(main())

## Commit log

2026-09-20 Initialize Hux wheeled-biped docs scaffold and requirements.
    Add vision, electronics, mechanical, and software docs with FC left TBD,
    Steve's stair-climbing requirements (~9.5" riser), first milestones, and
    empty cad/firmware/software trees. No locked hardware and no spend.
2026-09-20 Add RAI Roadrunner research note to the study packet.
    Watch-alongside Hattori: one-wheel balance, multimodal drive vs step, knee symmetry. Lab RL stack, not Hux's maker path. Docs only.
2026-09-20 Add FrRonconi student balancer to Steve's inspiration list.
    Both X shares are inspiration only: lab Roadrunner plus the 3-month two-leg/wheel student prototype (closer Hux early-R&D vibe). Docs only; FC TBD; no spend.
2026-09-20 Document electric-only, 4S LiPo class, and TBD hip/knee/wheel intent.
    Capture Steve's 2026-09-20 power and mechanical notes without locking
    actuators, inventing a PDB/BEC BOM, or adding pack/wheel SKUs.
2026-09-21 Consolidate open docs PRs #5–#15 and add a dated decision log.
    Merge unique content from the conflicting docs PRs onto current main, with later intent winning on actuators and mass. Hip roll stays in V1; knee and hip swing remain servo vs stepper+belt TBD; 4S pl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
2026-09-21 Add Tazer anti-pattern lessons into the consolidation docs.
    Steve asked to learn from the Tazer wheeled-biped video. Fold a research note plus pointers into this PR: GIM8108 stays a candidate only, carbon-tube path is confirmed, 4S still preferred, and power/LQR/TPU mistakes are logged as anti-patterns.
2026-09-21 Add Stompy CAD-to-sim-to-real research note.
    Capture Kayden Knapik's week-build walker lessons (shared CAD/home zero, URDF lockstep, resting-geometry gait bias, tether, outdoor domain gap) without requiring RL walking for Hux V1.
2026-09-21 Add Diablo wheeled-leg research note.
    Steve's ETA Prime / arXiv:2407.21500 share. Docs only: steal split brain,
    DD/QDD class, LQR/PID before RL, and height-as-state. Do not buy Diablo.
2026-09-21 Settle the foot at 6 inches and open a first-buy list.
    A 9.5 by 9.5 inch step only leaves room to pivot and place if the tire is about 6 by 1.25 inches. The first purchase is those tires, tubes, and carbon spar stock. Motors stay off the list.
2026-09-22 Widen the stance to 14 inches and add living drawings.
    The head stays inside that width and the wheels and legs sit outside it. The knee folds to the rear. The bill of materials now lists line prices, and $89.41 remains the only authorized order.
2026-09-22 Model the front-wheel catch, joint torques and sway in the stair climb.
    The living-drawings climb now rolls the front wheel back under the mass during the
    flight and catches the leftover after the crest, computes hip and knee torques for
    both legs, schedules the lateral sway with a front view, plays in real time, and has
    knobs that rebuild the step. docs/research/stair-climb-dynamics.md records what it
    says: a +-6% throw window on the settled geometry, land at the rear of the slot, body
    CoM 1-2 in ahead of the hips, knee ~10.6 N.m holding.
    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
2026-09-22 Plan: advisory Hux bot and a digital-twin horizon.
    Record Steve's 2026-09-22 operating mode, inventory-not-driver rule, and
    phased twin/dojo north star after classical balance. R14/R18 and the
    authorized BOM cart stay as they are.
2026-09-22 Play the stair climb in real time, and move the hardware list and data flow onto their own pages.
2026-09-22 Add a software page for the F765-Wing and the Pi 5.
    The living drawings now say what runs on each chip: no OS on the Wing, Raspberry Pi OS Lite on the Pi 5, CRSF on the Nano, and the ESP32 unused. ArduPilot comes off. The first image is a text stream,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
2026-09-22 Add a 3D sandbox to the living drawings.
    A new "3D sandbox" page (tools/living-drawings/sim.html) drives the working
    model in three.js with Rapier rigid-body physics. It uses the same kin.js
    geometry and lump masses as the 2D drawings. Every joint is a torque with a
    limit. The balance loop is an LQR on the lean of the mass over the axle, rebuilt
    as leg height changes. You can drive with keys, a gamepad or touch. The course
    has the 9.5" stair, two ramps, 1/2" and 1" sills, a 2" curb, wet tile and
    crates. HUD bars and 10 s charts show torque against each limit.
    npm test in that folder runs kin.js and a headless sim-test.js. It checks the
    engine workarounds and prints the findings: a 1" sill c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
2026-09-23 Give the sandbox a ride height, spring legs, a stumble catch and a planned one-wheel poise.
    Steve asked for ride-height control with a medium stance by default, leg suspension that
    lifts on impact, better stumble recovery, and a coordinated one-leg stand instead of the
    free leg kicking out.
    - Ride height defaults to 75% (hip 14.3" vs 16.8"), with Low / Medium / High presets and a slider.
    - Legs are a 3.5 Hz virtual spring-damper along hip-to-axle, with gravity feed-forward and roll damping.
    - An impact reflex and a stall hop lift the wheel over edges: the 1" sill now crosses at 0.5-1.0 m/s.
    - A capture-point leg catch and a hip-roll side step: sideways shove recovery 3 -> 5.5 N·s.
    - The on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
2026-09-24 Add SpdrBot Isaac Sim research note.
    Docs-only note on Indystry SpdrBot (4-leg spider, Isaac Sim/Lab,
    Fusion→URDF→USD, RL then hand gait). Steal pipeline lessons for the
    Phase E twin/dojo horizon; do not adopt spider morphology or stand up
    Isaac Lab before TWO_WHEEL. Indexed from inspiration, study-plan,
    research README, and a dated decisions entry. No spend, no SKU, no BOM.
2026-09-26 Log 2026-09-25 twin/hip/tire planning notes.
    Add the missing 2026-09-23 geometry/contact honesty pass to the
    decision log. Keep hip roll IN V1 and the twin pipeline TBD.
2026-09-26 Give the sandbox a real tire: shared round-crown profile and a carcass spring.
    tire.js holds one cross-section (full-round crown by default) that builds the Rapier
    hull, the Three.js lathe mesh and the 2D projection, so the flat-shoulder cylinder is
    gone and the contact walks the crown under camber (tested 0-30 deg). Each wheel is a hub
    plus a tread ring on a spring (tireK, tireZeta knobs); the HUD reports squish and the
    implied pad. The one-leg controller now pivots on the crown contact instead of the hub,
    which is what put the poise on its bail-out threshold. Docs and regression updated.
    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
2026-09-26 Review the bench software stack and the Jetson question.
    docs/research/compute-stack-review.md: F765-Wing has no CAN, so the
    actuator bus picks the P3+ MCU; the first image needs blackbox, live
    params, a framed link and a hardware torque cut; the Pi 5 is right for
    V1 and wrong for seven cameras; Jetson prices moved 2026-07-22 and the
    board is a P5 perception buy (Orin Nano Super dev kit), not V1.
    Claude-Session: https://claude.ai/code/session_01LsW1yJmGtCd2HkG9A1xPaT
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2026-09-26 Work the one-wheel stance: frontal-plane mechanics, why the stand fails, and the hop the stair needs.
    Steve 2026-09-26: the one-leg stand needs much more work, the hip-roll
    weight-shift mechanics are unclear, and the one-leg action does not work
    in the sandbox. New docs/research/one-leg-stance.md and a closed-form
    frontal-plane model (tools/living-drawings/frontal.js), checked against
    the Rapier sandbox: both give 24.7 deg of hip roll to put the mass over
    one crown contact at the 92% stance and an 8.3 N.m cantilever on the
    planted hip roll whenever a wheel is up (12-13 N.m peak through a hop).
    The static one-wheel stand is an acrobot with the body CoM at the hip
    axis: a 10 mm CoM error costs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
2026-09-26 Add the Teensy 4.1 CAN kit and anti-spark; shortlist RobStride actuators; put the pack on hold for 8S.
    Steve 2026-09-26: picked a 6S 5200 mAh 60C XT90 pack (then: somewhat
    random, smaller is fine, wants reasonable runtime), said add the
    anti-spark, add the CAN MCU, and asked what to consider for actuators.
    docs/research/actuator-shortlist.md: framework, 2026 candidates on
    Hux's numbers, CAN bus math (8 classic-CAN nodes need >=2 buses), and
    the finding that RobStride 00/01/02 have a 24 V floor, below 6S for most
    of the discharge -> recommend 8S 2700-3300 mAh. Shortlist RS02 knees,
    RS00 roll + swing, RS05 wheels. Teensy 4.1 + ICM-42688-P + 3x CAN
    transceivers and XT90-S added to the order-now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
2026-09-26 Hip roll shortlist: size for the 8.3 N·m hold from the one-leg stance study, not the poise.
    RS00 is out for hip roll. RS02 if the hip offset comes in to <= 3.5",
    RS06 at the drawn 5.4". The hip offset is now the first decision.
    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
2026-09-28 Add a drivable V1-PROOF 3D sandbox on the study's own simulator
    proof-sandbox.html loads tools/v1-proof/sim.js in the browser, so the
    driving feel comes from the same plant and LQR that produced the 388/391
    evidence. The lanes are the physical protocol's fixtures (3 deg grade and
    cross-slope, 5 mm bumps, 3 mm seam) plus the 20 mm challenge threshold.
    Shoves use the protocol pulses. Size references: 10 cm grid, a can, a
    letter sheet and the parked STAIR-V1 envelope. A leg-height slider gives
    a quasi-static preview between the pinned study poses.
    sim.js gains a UMD wrapper only. A full rerun reproduces every pass/fail,
    with numbers matching to 2e-13; the saved hash is updated. test_sandbox.js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
2026-09-29 Add V1-PROOF passive PLA print kit and build-plan links
    [01_layout_deck.stl, 02_fixed_pivot_plate.stl, 03_link_110.stl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]
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2026-10-04 Adopt Simplified Technical English for all active text
    All active text now obeys ASD-STE100 Simplified Technical English.
    The skill is vendored in tools/ste and linked from .claude/skills.
    docs/writing-standard.md gives the rules in short, the names table
    and the gate description. CLAUDE.md tells each session to read the
    skill and to run the gate.
    tools/ste/check_repo.py checks the active Markdown, the V1-PROOF plan
    data, the V1-PROOF page text and the text constants of build_site.py.
    npm run test:site runs the gate first and fails on a structural error.
    52 files went from 846 structural errors to zero. The archive, the
    research notes and the V0-GENESIS pages keep their original text. An
    i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
    [review.py]
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2026-10-14 Add R04 three-deck body kit and fit records
    R04 replaces the R03 body interfaces after the reported fit problems:
    matched walls, three decks, component mounts and an ST3215 cradle.
    Adds the R03 assembly record, the R04 fit review and the print records.
    Claude-Session: https://claude.ai/code/session_013pReJMucFtwCaRC45emW6c
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2026-10-14 Correct one STE paragraph in the R05 print record
    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
2026-10-15 Add the bench firmware, the kill chain design and the ST3215 arrival
    firmware/bench: Pico 2 C program for the electronics bench stages E0-E6.
    LSM6DSO over SPI1, PIO quadrature encoder, DRV8874 PH/EN PWM, modes
    DISARMED / BENCH_ARMED / FAULT, 250 ms deadman, 100 ms hardware
    watchdog, 500 Hz heartbeat on GP22, 50 Hz telemetry. Prebuilt
    hux_bench.uf2 (SDK 2.2.0, Arm GCC 15.2.1) and the host console
    tools/bench/hux_bench.py. No board test is recorded.
    docs/kill-chain.md: Pololu 2813 latched rail switch, momentary KILL
    button on OFF, ARM button gated by the heartbeat, charge-pump
    missing-pulse detector, parts list and stages K0-K6. Design only.
    The user reports two ST3215 servos received, label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
2026-10-15 Drop USB output after 2 ms so a stalled host cannot trip the watchdog
    PICO_STDIO_USB_STDOUT_TIMEOUT_US=2000 replaces the 500 ms default. A
    host that opens the port and stops reading would otherwise block the
    control loop past the 100 ms watchdog. Rebuilt hux_bench.uf2.
    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
2026-10-17 Add the R05 crank-and-pushrod leg drive and the plate 6 kit
    The ST3215 servos did not fit the R05 cradles. This revision replaces
    parts 13 and 14 with a servo frame inside each wall, a crank hub in a
    wall bushing, a pushrod to a boss on the upper link and two drill jigs
    for the printed walls. The CAD sweep checks the hub and the pushrod with
    both legs: crank sweep 69 degrees, transmission angles 55 to 90 degrees,
    minimum clearance 1.0 mm. The leg drive is optional for V1-PROOF, which
    keeps both legs locked at 30 degrees. The README gets a Leg drive
    heading so the site links resolve. Work of the 2026-10-16 session,
    reviewed and committed on 2026-10-17.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
2026-10-17 Open the R06 body plan and record the Rev C answers
    The user accepted the leg junction board, decided to desolder the Pico 2
    pins for direct XH headers, and accepted the 335 mm Pico-to-driver runs.
    The R06 plan collects the body corrections from the R05 build and from
    wiring atlas Rev C: walls with the leg-drive holes, 70 x 50 mm perfboard
    cassettes, a mount for the leg junction board, harness tie points, a tray
    for the measured pack, 45 degree gearmotor clearance and a KILL button
    position. It waits for the R05 measurements. The NOTES links into the
    local-only vendor folder become plain text so the site build is clean.
    Claude-Session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
